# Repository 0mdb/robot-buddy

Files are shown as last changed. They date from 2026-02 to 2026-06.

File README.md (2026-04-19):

# Robot Buddy

A kid-safe, expressive robot platform combining real-time motor control, an animated TFT face, and optional networked AI planner.

## How It Works

Two ESP32-S3 microcontrollers handle the deterministic, safety-critical work: one drives motors with PID control and enforces safety limits, the other renders an animated face on a 320x240 TFT touch display (`esp32-face`). A Raspberry Pi 5 orchestrates everything at 50 Hz — reading sensors, running the state machine, applying layered safety policies, and streaming telemetry to a browser UI. An optional AI planner server on a separate machine (3090 Ti) generates expressive behavior plans via a local LLM.

Reflexes are local and deterministic. Planner is remote and optional.

## Hardware

| Component | Hardware | Role |
|---|---|---|
| Supervisor | Raspberry Pi 5 | 50 Hz orchestration, safety policy, HTTP/WS API |
| Face MCU | ESP32-S3 (ES3C28P) | 320x240 TFT face renderer + touch/buttons telemetry |
| Reflex MCU | ESP32-S3 WROOM | Differential drive, PID, encoders, IMU, ultrasonic, safety |
| AI Server | PC with 3090 Ti (off-robot) | Planner/conversation LLM + TTS on LAN (`LLM_BACKEND=ollama|vllm`) |
| Motor Driver | TB6612FNG | Dual H-bridge for differential drive |
| Power | 2S LiPo | Split into dirty (motors) and clean 5V regulated rails |

## Repository Layout

```
robot-buddy/
├── supervisor/       # Python supervisor (Raspberry Pi 5, process-isolated workers)
│   ├── core/            # 50 Hz tick loop, state machine, safety, behavior engine
│   ├── devices/         # MCU clients (reflex, face), protocol, expressions
│   ├── io/              # Serial transport, COBS framing, CRC
│   ├── workers/         # Process-isolated workers (TTS, vision, AI)
│   ├── messages/        # NDJSON envelope, event/action types
│   ├── api/             # FastAPI HTTP/WebSocket server, param registry
│   ├── mock/            # Mock Reflex MCU for testing (PTY-based)
│   ├── tests/           # pytest test suite
│   └── pyproject.toml   # Package metadata, deps
├── server/              # AI planner server (3090 Ti, FastAPI + backend switch)
│   ├── app/             # FastAPI app, LLM/STT/TTS backends, prompts, schemas
│   ├── tests/           # pytest test suite
│   ├── Modelfile        # Legacy Ollama model config
│   └── pyproject.toml   # Package metadata, deps
├── esp32-face/       # Face MCU firmware (ESP32-S3, C/C++, ESP-IDF)
│   └── main/            # TFT face rendering + touch/buttons + USB protocol
├── esp32-reflex/        # Reflex MCU firmware (ESP32-S3, C/C++, ESP-IDF)
│   └── main/            # Differential drive, PID, IMU, safety, encoders
├── dashboard/           # React dashboard (Vite + TypeScript + Biome)
│   └── src/             # Components, hooks, stores, tabs
├── specs/               # Completed specifications (immutable reference)
├── docs/                # TODO, architecture, protocols, wiring, power, research
├── deploy/              # Deployment (systemd service, install/update scripts)
├── tools/               # Dev utilities (face sim V3, parity check)
└── training/            # Wake word model training
```

## Architecture

```
┌──────────────────────────────────────────────────────┐
│ On Robot                                             │
│                                                      │
│  ┌────────────────────────────────────────────────┐  │
│  │ Raspberry Pi 5 — Supervisor                    │  │
│  │                                                │  │
│  │  50 Hz tick loop:                              │  │
│  │    read telemetry → state machine → safety     │  │
│  │    policies → send commands → broadcast        │  │
│  │                                                │  │
│  │  HTTP API (:8080)  WebSocket (:8080/ws)        │  │
│  │  Vision process (separate OS process, 10-20Hz) │  │
│  └──────┬──────────────────────┬──────────────────┘  │
│         │ USB serial (COBS)    │ USB serial (COBS)   │
│  ┌──────▼──────┐        ┌─────▼───────┐             │
│  │ Reflex MCU  │        │  Face MCU   │             │
│  │ ESP32-S3    │        │  ESP32-S3   │             │
│  │             │        │             │             │
│  │ Motors, PID │        │ 320x240 TFT │             │
│  │ Encoders    │        │ Face +      │             │
│  │ IMU, Range  │        │ Touch UI    │             │
│  │ Safety      │        │             │             │
│  └─────────────┘        └─────────────┘             │
└──────────────────────────────────────────────────────┘
         │
         │ HTTP (LAN, optional)
         │
┌────────▼───────────────────────────┐
│ AI Server (3090 Ti PC)             │
│                                    │
│ FastAPI planner server             │
│ LLM backend: ollama | vllm         │
│ TTS: Orpheus (vLLM) + espeak shed  │
│ POST /plan / WS /converse /tts     │
└────────────────────────────────────┘
```

### State Machine

`BOOT` → `IDLE` → `TELEOP` / `WANDER` → `ERROR`

- **BOOT → IDLE**: automatic when Reflex MCU connects with no faults
- **IDLE → TELEOP/WANDER**: via `set_mode` command
- **Any → ERROR**: on disconnect, ESTOP, TILT, or BROWNOUT
- **ERROR → IDLE**: via `clear_error()` when Reflex is healthy

### Safety Policies (Defense in Depth)

1. Mode gate — no motion outside TELEOP/WANDER
2. Fault gate — any fault → zero twist
3. Reflex disconnect → zero twist
4. Ultrasonic range scaling (hard stop at 250 mm, 50% at 500 mm)
5. Stale range fallback (50% cap)
6. Vision confidence scaling
7. Stale vision timeout (500 ms)

Safety-critical enforcement also runs on the Reflex MCU itself (acceleration limits, command TTL, hard stop). The supervisor applies additional caps above this.

### Serial Protocol

Binary packets over USB serial with COBS framing:

```
[type:u8][seq:u8][payload:N][crc16:u16-LE]
```

For `esp32-face`, this protocol carries face state/gesture/system/talking commands and touch/button/status telemetry only. Audio transport is supervisor-side USB audio.

Auto-reconnect with exponential backoff (0.5s–5s). See `docs/protocols.md` for packet definitions.

## Tech Stack

| Component | Stack |
|---|---|
| Supervisor | Python 3.11+, asyncio, FastAPI, uvicorn, pyserial, OpenCV |
| AI Server | Python 3.11+, FastAPI, httpx, Pydantic, Ollama (compat) + vLLM (migration target) |
| ESP32 Firmware | C/C++, ESP-IDF (FreeRTOS), CMake |
| Build (Python) | Hatchling via pyproject.toml, uv for dependency management |
| Build (ESP32) | `idf.py build` (CMake), `source ~/esp/esp-idf/export.sh` |
| Dashboard | React 19, Vite, TypeScript, Zustand, TanStack Query |
| Tests | pytest, pytest-asyncio, Vitest |
| Linting | ruff (Python), clang-format + cppcheck (C++), Biome (TypeScript) |

## Getting Started

### Supervisor (Raspberry Pi 5)

```bash
cd supervisor
uv sync --group dev

# Run with mock hardware (no physical robot needed)
just run-mock

# Run with real hardware
just run

# Other options
uv run python -m supervisor --no-vision         # Disable vision worker
uv run python -m supervisor --http-port 8080    # Custom HTTP port
uv run python -m supervisor --planner-api http://10.0.0.20:8100 --robot-id robot-1
```

### AI Planner Server (3090 Ti PC)

```bash
# Install and run the server
cd server
uv sync --extra dev --extra llm --extra stt --extra tts

# Recommended testing profile (vLLM planner + CPU STT + espeak)
LLM_BACKEND=vllm STT_DEVICE=cpu TTS_BACKEND=espeak \
uv run --extra llm --extra stt --extra tts python -m app.main
```

The server starts on port 8100. See `server/README.md` for full API docs and configuration.

### ESP32 Firmware

Requires ESP-IDF toolchain.

```bash
cd esp32-face   # or esp32-reflex
idf.py build
idf.py flash
idf.py monitor
```

### Dashboard

```bash
just run-dashboard         # dev server with hot reload
just build-dashboard       # production build → supervisor/static/
```

## Development

All commands are available via `just` (see `justfile`):

```bash
just test-all              # run all tests (supervisor, server, dashboard)
just lint                  # check Python + C++ + dashboard
just lint-fix              # auto-fix formatting
just preflight             # full pre-commit check (lint + tests + parity)
just sim                   # run face simulator V3
just check-parity          # verify sim↔MCU constant alignment
```

### Mock Mode

The supervisor includes a PTY-based mock Reflex MCU (`supervisor/mock/mock_reflex.py`) that simulates serial communication, telemetry, and fault injection. Use `just run-mock` to run the full supervisor stack without any hardware.

### Dashboard

When the supervisor is running, open `http://<robot_ip>:8080` in a browser for:
- Live telemetry display with diagnostic tree
- Mode control (IDLE, TELEOP, WANDER)
- E-STOP button
- Face control (moods, gestures, talking, conversation state)
- Parameter tuning sliders (PID gains, speed limits, safety thresholds)
- Monitor tab (device health, comms, power, sensors, faults, workers)
- MJPEG video stream (if vision enabled)

### Configuration

**Supervisor** — YAML config file (schema in `supervisor/config.py`):
- Sections: serial, control, safety, network, logging, vision
- Default serial paths: `/dev/robot_reflex`, `/dev/robot_face` (via udev symlinks)

**AI Server** — environment variables:
- `LLM_BACKEND`, `VLLM_MODEL_NAME`, `LLM_MAX_INFLIGHT`, `PERFORMANCE_MODE`
- legacy compatibility: `OLLAMA_URL`, `MODEL_NAME`, `PLAN_TIMEOUT_S`, `TEMPERATURE`, `NUM_CTX`
- See `server/README.md` for the full table

**ESP32** — `sdkconfig.defaults` + `config.h` constants

## Supervisor API

| Endpoint | Method | Description |
|---|---|---|
| `/status` | GET | Current robot state (JSON) |
| `/params` | GET | Full parameter registry |
| `/params` | POST | Transactional parameter updates |
| `/actions` | POST | RPC: `set_mode`, `e_stop`, `clear_e_stop` |
| `/video` | GET | MJPEG stream (if vision enabled) |
| `/debug/devices` | GET | Device connection state |
| `/debug/planner` | GET | Planner state |
| `/debug/mcu_benchmark` | GET | MCU benchmark run status |
| `/ws` | WS | Telemetry stream (20 Hz, JSON) |
| `/ws/logs` | WS | Live log stream |

## AI Server API

| Endpoint | Method | Description |
|---|---|---|
| `/health` | GET | Server + selected LLM backend status |
| `/plan` | POST | Accept world state + `robot_id/seq/monotonic_ts_ms`, return plan + `plan_id` echo metadata |
| `/converse` | WS | Conversation stream (single active session per `robot_id`) |
| `/tts` | POST | Direct TTS with optional metadata (`robot_id`, `seq`, `monotonic_ts_ms`) |

Plan actions: `say(text)`, `emote(name, intensity)`, `gesture(name, params)`, `skill(name)` — planner proposes intent and supervisor executes deterministic skills.

## Supervisor Fallback Policy

| Failure condition | Immediate supervisor action | Motion policy | Face policy | Speech policy |
|---|---|---|---|---|
| `/plan` unreachable / non-200 | Mark planner disconnected; skip remote plan apply | Local deterministic only (`patrol_drift`/`avoid_obstacle`/safe stop) | `confused` gesture with cooldown | Cancel queued planner speech |
| `/converse` TTS fails mid-turn | Stop playback and clear talking flag | No change to motion authority | Show `thinking` briefly then restore previous mood | Attempt fallback backend once; if unavailable, skip speech |

## Project Status

### Working
- [x] Supervisor: 50 Hz control loop, state machine, safety policies, conversation state, mood choreography
- [x] Supervisor: serial transport with COBS framing, CRC, auto-reconnect, protocol v2 (timestamps + seq)
- [x] Supervisor: FastAPI HTTP/WebSocket API with telemetry streaming
- [x] Supervisor: process-isolated workers (TTS, vision, AI, ear)
- [x] Supervisor: mock Reflex MCU for hardware-free development
- [x] AI Server: FastAPI + vLLM planner (Qwen), conversation, TTS (Orpheus + espeak)
- [x] ESP32 Face: TFT face rendering, 13 moods, 13 gestures, conversation border, touch/button telemetry
- [x] ESP32 Reflex: motor control, PID, encoders, IMU, safety enforcement
- [x] Dashboard: React 19, live telemetry, face control, monitor tab, mode control
- [x] Voice pipeline: wake word ("hey buddy") + VAD → STT → LLM → TTS → face animation
- [x] WANDER mode driven by deterministic skills + planner intent
- [x] Deterministic telemetry: timestamps, sequence numbers, clock sync, raw packet logging

### In Progress
- [ ] Reflex MCU hardware commissioning (breadboard bring-up)
- [ ] Personality engine implementation (spec complete, implementation pending)

### Future
- [ ] Conversation memory / interaction history
- [ ] Wake word model improvements (recall 42% → 80%+)
- [ ] Additional modes: LINE_FOLLOW, BALL, CRANE, CHARGING
- [ ] Home Assistant integration
- [ ] Voice ID / speaker identification

See [docs/TODO.md](docs/TODO.md) for the detailed backlog and [specs/](specs/) for design specifications.

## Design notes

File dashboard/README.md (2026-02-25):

# Robot Buddy Dashboard

Web dashboard for the Robot Buddy supervisor. Replaces the old single-file HTML dashboard entirely — `npm run build` outputs to `supervisor/static/` which FastAPI serves at `/`.

## Quick Start

### Development (with hot reload)

```bash
cd dashboard
npm install
npm run dev
```

Opens at `http://localhost:5173/`. Vite proxies all API/WS calls to the Pi at `192.168.55.100:8080` (configured in `vite.config.ts`).

### Production Build

```bash
cd dashboard
npm run build
```

Outputs to `../supervisor/static/`. The supervisor serves it automatically — no separate web server needed.

## Tabs

| Tab | What it does |
|---|---|
| **Drive** | Joystick (touch + mouse), mode buttons (IDLE/TELEOP/WANDER), E-STOP, sparkline gauge cards (speeds, gyro, range, battery, tick dt), fault badges, speed caps, video feed toggle |
| **Telemetry** | 4 uPlot time-series charts (wheel speeds, rotation, range, battery) with adjustable window (30s/60s/120s) and pause/resume |
| **Devices** | Reflex/Face MCU cards (packet counts, seq, age), clock sync (offset, RTT, drift), transport stats. Polled at 2s via `/debug/devices` + `/debug/clocks` |
| **Logs** | Live log stream via `WS /ws/logs`. Virtualized list (react-window, 5000 entries). Level filter buttons, text search, edge-aware pin auto-scroll (top in `Newest`, bottom in `Oldest`), click-to-expand detail panel |
| **Calibration** | PID tuner (kV, kS, Kp, Ki, K_yaw + rate limits), Vision/HSV sliders, Range thresholds, IMU panel. Debounced 150ms with Apply for batch updates |
| **Parameters** | AG Grid table of all params. Grouped by owner, quick filter search, inline edit with debounced POST, safety badges |
| **Face** | Mood/intensity/gaze/brightness, 13 gesture buttons, system mode, talking + energy, 7 flag toggles, manual lock |

## Tech Stack

| Concern | Library |
|---|---|
| Framework | React 19 + TypeScript |
| Build | Vite 7 |
| State | Zustand 5 |
| Data fetching | React Query 5 (debug endpoints, params) |
| Charts | uPlot (imperative, ~35 KB, bypasses React for 20 Hz data) |
| Tables | AG Grid Community 35 (params) |
| Virtualized lists | react-window 2 (log viewer) |
| Styling | CSS Modules (dark theme) |

## Architecture

### Data Flow

```
Pi supervisor (50 Hz tick loop)
  └─ WS /ws ──── 20 Hz telemetry JSON ────► wsManager.ts ──► telemetryStore (Zustand)
  └─ WS /ws/logs ── log entries JSON ──────► wsLogs.ts ────► logStore (Zustand)
  └─ REST /debug/* ── polled 2s ───────────► React Query ──► DevicesTab / ClocksTab
  └─ REST /params ── on demand ────────────► React Query ──► ParamsTab (AG Grid)
```

### Key Design Decisions

- **Float64Array ring buffers** — 1200 samples per metric (60s @ 20Hz), zero GC pressure during ingestion
- **Charts bypass React** — uPlot updates via `zustand.subscribe()` at 5 Hz, no React reconciliation
- **Gauges throttled to 10 Hz** — `useTelemetry(selector, 100)` hook with `useSyncExternalStore`
- **Joystick uses throttle (not debounce)** — steady 10 Hz while dragging, immediate `{v:0, w:0}` on release
- **WebSocket reconnect with exponential backoff** — 0.5s to 8s cap, `ws_connected` only after first valid telemetry
- **Page Visibility API** — ring buffers keep filling when tab is backgrounded, charts force redraw on foreground return
- **Cache headers** — `index.html` served with `no-cache`; hashed asset filenames are safe to cache forever

## Project Structure

```
dashboard/
├── src/
│   ├── App.tsx                    # Tab layout, WS lifecycle
│   ├── types.ts                   # All TypeScript interfaces
│   ├── constants.ts               # Faults, moods, gestures, face flags
│   ├── stores/
│   │   ├── telemetryStore.ts      # Snapshot + ring buffers + WS meta
│   │   └── uiStore.ts            # Active tab, video toggle
│   ├── lib/
│   │   ├── ringBuffer.ts         # Float64Array circular buffer
│   │   ├── wsManager.ts          # WS with reconnect + backoff
│   │   ├── wsLogs.ts             # Log WS + log store
│   │   ├── throttle.ts           # Joystick throttle
│   │   └── debounce.ts           # Slider/param debounce
│   ├── hooks/
│   │   ├── useTelemetry.ts       # Throttled selector
│   │   ├── useWsMeta.ts          # WS health (age, gaps, reconnects)
│   │   ├── useSend.ts            # WS command sender
│   │   ├── useDevices.ts         # React Query: /debug/devices
│   │   ├── useClocks.ts          # React Query: /debug/clocks
│   │   └── useParams.ts          # React Query: /params GET + POST
│   ├── components/
│   │   ├── Header.tsx            # WS status, telemetry age, faults
│   │   ├── TabBar.tsx            # 7-tab navigation
│   │   ├── Sparkline.tsx         # Tiny uPlot (transient updates)
│   │   ├── TimeSeriesChart.tsx   # Full uPlot (transient updates)
│   │   ├── Joystick.tsx          # Canvas, touch + mouse
│   │   └── FaultBadges.tsx       # Decoded fault flags
│   ├── tabs/                     # One file per tab
│   └── styles/                   # CSS Modules (dark theme)
├── vite.config.ts                # Build → ../supervisor/static/
└── package.json
```

## Scripts

```bash
npm run dev          # Vite dev server with HMR + proxy to Pi
npm run build        # TypeScript check + production build
npm run typecheck    # TypeScript only (no emit)
npm run lint         # Biome lint
npm run lint:fix     # Biome lint + autofix
npm run format       # Biome format
npm run test         # Vitest
npm run preview      # Preview production build locally
```

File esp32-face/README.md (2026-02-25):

# esp32-face

ESP32-S3 firmware for Robot Buddy face rendering + supervisor link.

## Scope

- Face animation renderer (landscape 320×240, ILI9341)
- Sim V3 animation parity target (13 moods, gestures, system face screens, talking modulation)
- USB CDC command/telemetry protocol
- Touch telemetry + corner button hit-testing
- Pixel-rendered corner button controls (SDF icons, not LVGL widgets):
  - bottom-left `PTT` (MIC icon, 60×46 px zone, tap-toggle listening)
  - bottom-right `ACTION` (X_MARK icon, 60×46 px zone, click event)
  - Icon/state/color driven automatically by conversation state
  - Suppressed (hidden + hit-testing disabled) during system overlays
- Conversation border renderer (SDF frame + glow, 8 conv states)
- WS2812 status LED:
  - talking: orange
  - listening: blue
  - idle: green

Audio codec/microphone handling was removed from this firmware. Audio is owned by supervisor-side USB devices.

## System Screens

System modes drive Buddy's face expression (eyes, mouth, eyelids, color) rather than abstract overlays — matching the Sim V3 approach. Implemented in `system_face.cpp`:

| Mode | Expression | Color | Duration |
|---|---|---|---|
| BOOTING | Sleepy slits → yawn → blink → happy bounce | Navy → cyan | 3.0 s |
| ERROR_DISPLAY | Confused face + slow headshake | Warm orange | Continuous |
| LOW_BATTERY | Sleepy with droopy eyelids + periodic yawns | Navy (dims with charge) | Continuous |
| UPDATING | Thinking expression, gaze drifts up-right | Blue-violet | Continuous |
| SHUTTING_DOWN | Yawn → droop → eyes close → fade to black | Cyan → navy → black | 2.5 s |

Small SDF icon overlays appear in the lower-right corner: warning triangle (error), battery bar (low battery), progress bar (updating).

The legacy abstract overlay renderer (`system_overlay_v2.cpp`) is retained but no longer called from the render path.

## Command Path Reliability

- `SET_STATE`, `SET_SYSTEM`, `SET_TALKING` use latched channels (latest value wins).
- `GESTURE` uses a FIFO queue for one-shot animations.
- This prevents high-rate talking energy updates from dropping mood/system/gesture commands.

## Rendering Note

- The face canvas uses explicit `LV_COLOR_FORMAT_RGB565` to match the ILI9341 panel format.
- This keeps the render path in native panel format and avoids extra color conversion work.

## Current Parity Gaps

- Face center rendering is not pixel-for-pixel with sim V3 (SDF eye/mouth rasterization differences remain)
- Some sim↔MCU timing divergences documented in [docs/TODO.md](../docs/TODO.md)
- Stage 4 firmware optimization planned (dirty-rect, DMA, RGB565 dithering)

## Protocol

Commands (host → face):

- `0x20` `SET_STATE` — mood, intensity, gaze, brightness
- `0x21` `GESTURE` — one-shot animation (FIFO queue)
- `0x22` `SET_SYSTEM` — system mode + param (boot, error, battery, updating, shutdown)
- `0x23` `SET_TALKING` — lip sync (talking flag + energy)
- `0x24` `SET_FLAGS` — feature toggles (blink, wander, sparkle, afterglow, edge glow)
- `0x25` `SET_CONV_STATE` — conversation border state (0–7)

Telemetry (face → host):

- `0x90` `FACE_STATUS` (20 Hz, v1=4B or v2=12B with command-causality fields)
- `0x91` `TOUCH_EVENT` (on change)
- `0x92` `BUTTON_EVENT` (on change)
- `0x93` `HEARTBEAT` (1 Hz, 68B base + optional perf tail)

## Build

```bash
idf.py build
```

## Flash + Monitor

```bash
idf.py -p /dev/ttyACM0 flash monitor
```

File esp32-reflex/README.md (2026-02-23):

# esp32-reflex

ESP32-S3 (Reflex MCU) firmware: owns motors, encoders, and safety.

Design goal: **deterministic motion control** with reliable feedback, smooth starts/stops, and hard safety guarantees. Supervisor (Raspberry Pi 5) sends high-level velocity targets; MCU owns PWM, PID, and stop behavior.

---

## Framework
- ESP-IDF (FreeRTOS)
- Motors: LEDC PWM + GPIO direction into TB6612FNG
- Encoders: PCNT (quadrature) for each wheel
- Control loop: 100–200 Hz speed PID (closed-loop)
- Transport: USB serial (binary protocol)

---

## Hardware
- Differential drive (left/right motors)
- TT gear motors with integrated quadrature encoders
- Motor driver TB6612FNG
- 2S battery pack
- BMI270 IMU (gyro + accelerometer, 400 Hz ODR)
- Ultrasonic range sensor

---

## Control Philosophy
### Reflexes stay local
- The MCU is responsible for **stable motion** regardless of supervisor load.
- No real-time PWM from supervisor. Ever.

### Interfaces are narrow and stable
- Supervisor commands *intent*: `SET_TWIST(v, w)`, `STOP()`
- MCU returns *truth*: wheel speed, gyro, battery, faults

---

## Motion Stack (v1)
1) **Command layer**
- `SET_TWIST(v_mm_s, w_mrad_s)` target
- Convert to wheel speed targets using wheelbase & wheel radius

2) **Rate limiting**
- Acceleration / jerk limiting on wheel targets
- Prevents brownouts, reduces stalls, kid-safe motion

3) **Speed PID (per wheel)**
- Inputs: encoder counts over dt
- Output: PWM duty (signed)
- Anti-windup + output saturation
- Deadband compensation (optional)

4) **Safety**
- Command timeout -> controlled stop (ramp down)
- Watchdog
- Fault flags -> forced stop

---

## Advanced Features (only if they earn their keep)
### A) Slip / traction heuristics (low-cost, optional)
Without an IMU, "traction control" is limited. What we *can* do:
- Detect wheel-speed mismatch under commanded straight motion
- Detect stall (commanded speed high, measured ~0 for N ms)
- Apply corrective action:
  - reduce accel
  - clamp max PWM
  - pulse-retry pattern
This is practical and improves robustness, but it’s not true traction control.

### B) IMU-assisted yaw damping (implemented)
BMI270 IMU is integrated. Current implementation:
- Gyro-Z feedback for yaw damping in the control loop
- 400 Hz ODR, ±500 dps gyro range, ±4g accel range

### C) Battery-aware torque limiting (high leverage)
- Monitor battery voltage
- If sag detected: reduce accel / max PWM to avoid Pi 5 brownouts
This is *very* useful in kid scenarios (stalls, carpet, low battery).

### D) Odometry (recommended once encoders are stable)
- Integrate wheel distances -> (x, y, theta)
- Provide odom to Pi 5 for higher-level behavior
Note: odom on tracks drifts; still valuable.

---

## Protocol (Supervisor ↔ Reflex MCU)
Binary packets, fixed-size, no JSON.

### Commands
- `SET_TWIST(v_mm_s: i16, w_mrad_s: i16)`
- `STOP(reason: u8)`
- `SET_MODE(mode: u8)` (future: safe/normal/turbo)
- `SET_LIMITS(max_v, max_a, max_pwm)` (optional)

### Telemetry
- wheel_speed_l/r (i16)
- encoder_counts_l/r (i32)
- battery_mv (u16) (optional but recommended)
- fault_flags (u16)
- (future) odom x/y/theta

---

## Tasks / Timing (suggested)
- `usb_serial_task`: parse commands, publish targets
- `control_task` @ 100–200 Hz:
  - read encoders (PCNT snapshot)
  - compute wheel speeds
  - apply rate limit
  - run PID
  - write PWM + direction
- `safety_task` @ 10–50 Hz:
  - command timeout
  - battery checks
  - fault handling
- optional `telemetry_task` @ 10–20 Hz

No blocking in the control loop.

---

## Fault Model (v1)
- `FAULT_CMD_TIMEOUT`
- `FAULT_ENCODER_MISSING`
- `FAULT_STALL_LEFT / FAULT_STALL_RIGHT`
- `FAULT_BATT_LOW` (if battery sense)
- `FAULT_ESTOP`

Faults force stop or limit mode depending on severity.

---

## Completed
- [x] Motor driver pinout + open-loop control (LEDC PWM + GPIO direction into TB6612FNG)
- [x] Encoders with PCNT (quadrature, per wheel) + wheel speed measurement
- [x] Per-wheel FF+PI speed control @ 100 Hz
- [x] Acceleration limiting / ramping (kid-safe, power-safe)
- [x] Stall detection + safe recovery
- [x] STOP behavior (ramped stop, brake/coast)
- [x] Command timeout → safe stop
- [x] Watchdog integration (esp_task_wdt)
- [x] E-stop + fault flags → forced stop
- [x] USB serial binary protocol (COBS + CRC16) to supervisor
- [x] Telemetry packets (STATE: speeds, gyro, battery, faults, range)
- [x] BMI270 IMU integration (gyro-Z yaw damping)

## TODO

See [docs/TODO.md](../docs/TODO.md) for the full backlog. Key remaining items for reflex:
- Battery voltage sense (ADC) + sag-aware limiting
- Odometry integration (x, y, theta)
- Full IMU heading hold PID (currently gyro damping only)
- Hardware commissioning (Phases 1-5)

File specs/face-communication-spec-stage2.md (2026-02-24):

# Face Communication Spec — Stage 2: Full Specification

**Prerequisite**: Stage 1 (Research & Design Approach Proposal) — all decisions approved 2026-02-21.

**Scope**: This document defines the complete visual language for the robot face — every expression, transition, timing rule, and protocol mapping needed to implement "intention and awareness" for children ages 4–6. All values are implementation-ready. All claims are evidence-tagged per Stage 1 rigor constraints.

**Companion documents**: Stage 2 Implementation Plan, Stage 2 Evaluation Plan (separate files).

---

## 1. Personality Profile

**Relational role**: Caretaker/guide with playful elements. Predominantly calm and reassuring. Emotional authority is higher than the child's — the robot's affect should not destabilize.

**Axis positions** (0.0 = low end, 1.0 = high end per [S1-C3] definitions):

| Axis | Position | Rationale |
|---|---|---|
| **Energy Level** | 0.40 | Calm baseline with enough responsiveness to feel warm, not sluggish. Caretaker pacing — slightly slower than the child's energy. **[Inference]** |
| **Emotional Reactivity** | 0.50 | Moderate — expressive enough to validate the child's emotions, restrained enough not to mirror distress. **[Empirical]** Kahn et al. (2012) shows children attribute real feelings to robots. **[Inference]** We set reactivity at 0.50 to prevent over-attribution while remaining warm. Must be validated in T4 child evaluation. |
| **Social Initiative** | 0.30 | Mostly responsive. Initiates only through idle aliveness cues (breathing, gaze wander), not through autonomous mood changes or attention-seeking gestures. **[Empirical]** Leite et al. (2013) notes proactive behaviors sustain engagement but risk habituation. **[Inference]** We set initiative at 0.30 to stay responsive without risking habituation. |
| **Vulnerability Display** | 0.35 | Lightly guarded. Can show confusion (THINKING mood) and mild concern but avoids overt sadness, fear, or anger outside conversation context. Consistent with caretaker authority. **[Inference]** |
| **Predictability** | 0.75 | High consistency. Same conversation phase → same core face behavior. Variation limited to cosmetic parameters per D10:B. **[Empirical]** Kanda et al. (2004) shows consistency builds trust over repeated interactions. **[Inference]** We set predictability at 0.75, reserving 0.25 for cosmetic variation (blink, breathing, sparkle) that provides aliveness without semantic variability. |

**Design implications of this profile**:
- Transitions are smooth, never snappy (Energy 0.40)
- Emotional onset is gradual, not instant (Reactivity 0.50)
- Robot never autonomously changes mood outside conversation (Initiative 0.30)
- Negative emotions are always brief, contextualized, and recovered (Vulnerability 0.35)
- A child who interacts daily should develop reliable expectations (Predictability 0.75)

---

## 2. Intent Taxonomy

Everything the face must communicate, classified by temporal profile.

### 2.1 Tonic Intents (Sustained States)

Held for extended periods. The face "rests" in one of these.

| Intent | Description | Primary Channel | Duration |
|---|---|---|---|
| **Idle** | Robot is on, no conversation active | Eyes (neutral) + breathing + blink + gaze wander | Indefinite |
| **Conversation: Listening** | Child is speaking, robot is attending | Gaze (center lock) + border (teal breathing) + LED | Until VAD end-of-utterance |
| **Conversation: PTT** | Tap-to-talk active | Gaze (center lock) + border (amber steady) + LED | Until toggled off |
| **Conversation: Thinking** | Processing user input | Gaze (aversion) + border (blue-violet orbit) + LED | Until TTS starts (~1–3 s typical) |
| **Conversation: Speaking** | TTS playback active | Mouth (lip sync) + border (white-teal energy) + LED | Until TTS finishes |
| **Emotion** | AI/planner-set mood | Eyes + mouth + face color | Until next mood command or recovery |
| **System overlay** | BOOTING, ERROR, LOW_BATTERY, UPDATING, SHUTTING_DOWN | Face-based expression + status icon (§4.4) | Until condition clears |

### 2.3 Layer Interaction Rules

The conversation layer can temporarily **clamp** the emotion layer during specific phases. This resolves the tension between emotion as a tonic intent ("until next mood command") and conversation states that force specific moods.

| Conversation Phase | Emotion Layer Status | Behavior |
|---|---|---|
| **LISTENING / PTT** | Suppressed | Face shows attentive neutral (NEUTRAL @ 0.3). The personality worker continues integrating AI emotion impulses into the affect vector, but the tick loop does not display the worker's projected mood during this phase. |
| **THINKING** | Suppressed | Face shows THINKING mood @ 0.5. The personality worker continues integrating impulses. |
| **SPEAKING** | **Active** | Tick loop reads the personality worker's current snapshot and displays its projected mood via mood switch choreography (§5.1.1). The snapshot already reflects all impulses integrated during LISTENING/THINKING — no explicit queue or replay step. |
| **ATTENTION** | Held | Current mood held unchanged. |
| **ERROR** | Held | Current mood held unchanged. |
| **DONE** | Released | Mood intensity ramps to 0.0 (return to neutral). The personality worker's affect vector decays naturally toward baseline. Emotion layer returns to idle control. |

**Rationale**: During LISTENING and THINKING, the child sees the robot "paying attention" and "processing" — these are social signals that should not be contaminated by premature emotion display. Emotions become visible during SPEAKING, when the audio context makes them legible (per Denham, 1986: children use context + face together).

**Suppress-then-read model**: The personality worker's affect integrator runs continuously during LISTENING/THINKING (PE spec §10). AI emotion impulses are integrated immediately — they are never buffered in a queue. The integrator provides natural smoothing: if the AI sends HAPPY during LISTENING and then SAD during THINKING, the affect vector ends up between them (weighted by decay and recency), producing emotionally coherent behavior. On SPEAKING entry, the tick loop reads the worker's current snapshot, which already reflects all integrated impulses.

### 2.2 Phasic Intents (Transient Events)

Brief events that overlay or punctuate tonic states.

| Intent | Description | Duration | Trigger |
|---|---|---|---|
| **Acknowledgment** | "I heard you" response to wake word or PTT press | 400 ms | Wake word detection / PTT down |
| **Mood transition** | Choreographed switch between emotions | 350–550 ms | SET_STATE with new mood_id |
| **Conversation phase transition** | Visual bridge between conversation states | 200–500 ms | State machine edge |
| **Gesture** | One-shot expressive animation (blink, nod, laugh, etc.) | 180 ms – 3.0 s | GESTURE command |
| **Negative affect recovery** | Mandatory return to neutral/positive after negative mood | 300–500 ms | Guardrail timer expiry |
| **Error flash** | Brief visual error indicator | 800 ms | Conversation error event |

---

## 3. Channel Allocation Policy

**Policy**: Hybrid ([S1-C4], informed by [S1-D1]:A, [S1-D3]:C, [S1-D5]:A, [S1-D6]:C).

### 3.1 Channel Ownership Table

| Channel | Emotion Layer | Conversation Layer | System Layer | Idle Layer |
|---|:---:|:---:|:---:|:---:|
| **Eyes (shape, eyelids)** | OWNS | mood hints only | overlay | neutral defaults |
| **Mouth (curve, open, width)** | OWNS | — | overlay | neutral defaults |
| **Gaze (eye position)** | — | All active conv states (extended from D6:C) | — | OWNS (wander) |
| **Face color** | OWNS | — | overlay | neutral color |
| **Border** | — | OWNS | — | off |
| **LED** | — | OWNS (mirrors border) | override | off |
| **Backlight** | — | — | OWNS | default brightness |

**Collision rules** (highest priority wins):
1. System overlay → overrides everything
2. Talking animation → overrides mouth (lip sync), coexists with emotion eyes
3. Conversation gaze → overrides idle gaze wander during all active conversation states (ATTENTION, LISTENING, PTT, THINKING, SPEAKING, ERROR). [S1-D6]:C specified "hybrid, incrementally extensible" — extended to all states for coherence.
4. Conversation border/LED → independent channel, no collision with emotion
5. Emotion → sets eyes/mouth/face color
6. Idle → fills anything not claimed above

### 3.2 Semantic vs Cosmetic Parameters (D10:B)

**Semantic** (deterministic — same input → same output):
- Mood selection (mood_id)
- Mood intensity target
- Conversation state (border color, animation type)
- Gaze target during LISTENING (center)
- Gaze direction during THINKING (aversion target)
- Transition choreography sequence
- Negative affect guardrail timers

**Cosmetic** (bounded stochastic — jitter permitted):
- Blink interval (2.0–5.0 s, uniform random)
- Idle gaze wander target (random within ±MAX_GAZE)
- Idle gaze wander interval (1.5–4.0 s, uniform random)
- Saccade micromotion (existing MCU implementation)
- Breathing phase (continuous, free-running)
- Sparkle activation (Bernoulli per frame, p=0.05)
- Sparkle position (uniform random across screen)

---

## 4. Visual Grammar

### 4.1 Emotion Expressions

#### 4.1.1 Mood Classification

| Class | Moods | Autonomous Use | Guardrails |
|---|---|---|---|
| **Positive** | HAPPY, EXCITED, LOVE, SILLY | Unrestricted | None |
| **Neutral** | NEUTRAL, CURIOUS, THINKING, SLEEPY, SURPRISED, CONFUSED | Unrestricted | SURPRISED: startle reflex safety (§7.4) |
| **Negative** | SAD, SCARED, ANGRY | Conversation context only (D2:B) | See §7 |

**[Empirical]** Widen & Russell (2003): Children ages 4–6 reliably label happy, sad, angry, scared. Surprise and disgust are often confused. This informs the "safe set" — HAPPY, SAD, ANGRY, SCARED are the most legible. SURPRISED requires extra disambiguation via context.

**SURPRISED reclassification**: PE spec §4.1 places SURPRISED at (V=+0.15, A=+0.80) — positive valence, high arousal. Classifying it as Neutral is more principled than the original Negative classification, since surprise is positive-valent and often positive-contextual. High arousal warrants a safety cap (§7.4), but not a negative-affect guardrail.

**CONFUSED**: Added per PE spec §4.1 (V=-0.20, A=+0.30). Mild negative valence, low arousal — conveys uncertainty without distress. Classified as Neutral because the expression reads as "uncertain/puzzled" rather than "upset."

**[Empirical]** Di Dio et al. (2020): On stylized robot faces, children 4–8 achieve 68–99% recognition accuracy. Happiness and sadness are easiest (>90%); anger and fear are moderate (70–85%); surprise is hardest (<70%).

#### 4.1.2 Mood Parameter Targets

All parameters blend from neutral baseline via intensity (§4.1.3). Values are the full-intensity (1.0) targets.

| Mood | mouth_curve | mouth_width | mouth_open | lid_slope | lid_top | lid_bot | Face Color (R,G,B) |
|---|:---:|:---:|:---:|:---:|:---:|:---:|:---:|
| NEUTRAL | 0.1 | 1.0 | 0.0 | 0.0 | 0.0 | 0.0 | (50, 150, 255) |
| HAPPY | 0.8 | 1.1 | 0.0 | 0.0 | 0.0 | 0.4 | (0, 255, 200) |
| EXCITED | 0.9 | 1.2 | 0.2 | 0.0 | 0.0 | 0.3 | (100, 255, 100) |
| CURIOUS | 0.0 | 0.9 | 0.0 | -0.3 | 0.0 | 0.0 | (255, 180, 50) |
| SAD | -0.5 | 1.0 | 0.0 | -0.6 | 0.3 | 0.0 | (50, 80, 200) |
| SCARED | -0.3 | 0.8 | 0.3 | 0.0 | 0.0 | 0.0 | (180, 50, 255) |
| ANGRY | -0.6 | 1.0 | 0.0 | 0.8 | 0.4 | 0.0 | (255, 0, 0) |
| SURPRISED | 0.0 | 0.4 | 0.6 | 0.0 | 0.0 | 0.0 | (255, 255, 200) |
| SLEEPY | 0.0 | 1.0 | 0.0 | -0.2 | 0.6 | 0.0 | (40, 60, 100) |
| LOVE | 0.6 | 1.0 | 0.0 | 0.0 | 0.0 | 0.3 | (255, 100, 150) |
| SILLY | 0.5 | 1.1 | 0.0 | 0.0 | 0.0 | 0.0 | (200, 255, 50) |
| THINKING | -0.1 | 1.0 | 0.0 | 0.4 | 0.2 | 0.0 | (80, 135, 220) |
| CONFUSED | -0.2 | 1.0 | 0.0 | -0.15 | 0.1 | 0.0 | (200, 160, 80) |

**CONFUSED design rationale**: Mild furrowed brow (lid_slope -0.15), slightly raised upper lid (0.1). Very slight frown (mouth_curve -0.2), mouth closed. Warm amber-brown face color, distinct from all other moods. Less expressive than CURIOUS (lid_slope -0.3) to convey "uncertain" rather than "interested." Note: the CONFUSED *gesture* (GestureId::CONFUSED = 3) already exists and is distinct from this sustained *mood*. **[Provisional]** Parameters need sim prototyping in Stage 3 and child recognition testing in T3/T4 evaluation.

*Source: Verified from `face_state.cpp:257–321` and `face_state.cpp:620–680`.*

#### 4.1.3 Intensity Blending

**Mechanism** (D8:C — discrete with intensity blending):

```
displayed_value = neutral_value + (mood_target - neutral_value) × intensity
```

Applied identically to all 6 face parameters and to face color (RGB channels independently).

**Neutral baseline values**:
- mouth_curve: 0.1, mouth_width: 1.0, mouth_open: 0.0
- lid_slope: 0.0, lid_top: 0.0, lid_bot: 0.0
- Face color: (50, 150, 255) — cyan-blue

**Intensity range**: 0.0 (fully neutral) to 1.0 (full expression). Wire encoding: uint8 0–255.

**Typical intensity values**:
- AI conversation emotion: 0.7 (allows headroom for gesture overlay)
- Planner emotion: 0.5–1.0 (context-dependent)
- Recovery target: 0.0 (returns face to neutral)

### 4.2 Conversation State Signaling

**[Empirical]** Löffler et al. (2018): Color + motion multimodal coding offers the best cost/benefit ratio for robot emotion expression. Redundant cues across channels improve recognition. This supports the multimodal approach (D3:C) — border + LED + gaze + mood hints for each state.

**[Empirical]** Andrist et al. (2014): Gaze aversion during cognitive processing (thinking) is expected by humans and helps regulate turn-taking. Direct gaze during listening signals attention.

#### 4.2.1 State Definitions

Eight conversation states, matching the sim prototype (`conv_border.py:25–33`):

```
IDLE → ATTENTION → LISTENING → THINKING → SPEAKING → DONE → IDLE
                 ↘ PTT ↗                  ↗ ERROR ↗
```

#### 4.2.2 Per-State Visual Specification

**IDLE** (no conversation active)

| Channel | Behavior |
|---|---|
| Border | Off (alpha = 0) |
| LED | Off (0, 0, 0) |
| Gaze | MCU idle wander (1.5–4.0 s interval, spring dynamics) |
| Mood | Last set mood, or NEUTRAL if none |
| Flags | All idle defaults: IDLE_WANDER=1, AUTOBLINK=1, SPARKLE=1 |

---

**ATTENTION** (wake word detected or PTT first press — acknowledgment phase)

| Channel | Behavior |
|---|---|
| Border | Flash to light cyan (180, 240, 255), inward sweep animation over 400 ms |
| LED | Light cyan at 16% border alpha |
| Gaze | Snap to center (0, 0) — supervisor sends gaze override |
| Mood | Hold current mood (no change) |
| Flags | IDLE_WANDER=0 (disable wander for gaze lock) |
| Duration | 400 ms, then auto-advance to LISTENING |

**Awareness indicators addressed**: Acknowledgment (immediate visual response to wake word), temporal correlation (face changes synchronized with trigger).

**Timing budget**: Wake word detection latency (~80 ms frame + inference) + supervisor event propagation (~20 ms tick) + MCU render (~33 ms) = ~133 ms worst case from speech end to first visible pixel change. Well within the 200–300 ms perceptual threshold for "immediate" response. **[Inference — needs measurement]**

---

**LISTENING** (child is speaking, robot is attending)

| Channel | Behavior |
|---|---|
| Border | Teal (0, 200, 220), breathing alpha: 0.6 + 0.3 × sin(t × 2π × 1.5) |
| LED | Teal at 16% of border alpha |
| Gaze | Center lock (0, 0) — supervisor overrides MCU idle wander (D6:C) |
| Mood | NEUTRAL at intensity 0.3 (attentive neutral — slight engagement) |
| Flags | IDLE_WANDER=0, AUTOBLINK=1 |

**Awareness indicators addressed**: Gaze coherence (eyes locked on user), state continuity (steady breathing border).

**[Empirical]** Admoni & Scassellati (2017): Direct gaze signals attention and willingness to engage. During listening, the robot's gaze should be directed at the speaker.

---

**PTT** (tap-to-talk — variant of listening, toggled on/off by tapping PTT button)

| Channel | Behavior |
|---|---|
| Border | Warm amber (255, 200, 80), subtle pulse: 0.8 + 0.1 × sin(t × 2π × 0.8) |
| LED | Amber at 16% of border alpha |
| Gaze | Center lock (0, 0) |
| Mood | NEUTRAL at intensity 0.3 |
| Flags | IDLE_WANDER=0, AUTOBLINK=1 |

Visually distinct from LISTENING (amber vs teal) so the child/parent can confirm PTT is active. Same gaze and mood behavior.

---

**THINKING** (processing user input, waiting for AI response)

| Channel | Behavior |
|---|---|
| Border | Blue-violet (120, 100, 255), orbiting comet dots: 3 dots, 0.5 rev/s, base alpha 0.3 |
| LED | Blue-violet at 16% of border alpha |
| Gaze | Aversion — look up-right (gaze_x = +0.5, gaze_y = -0.3) — supervisor sends explicit target |
| Mood | THINKING at intensity 0.5 (mild: slight lid droop + slight frown) |
| Flags | IDLE_WANDER=0, AUTOBLINK=1 |

**[Empirical]** Andrist et al. (2014): Gaze aversion during processing is natural and expected. Looking away signals "I'm working on it" rather than "I'm ignoring you." The key finding is that *away* matters, not which specific direction. **[Theory]** Up-right is the conventional direction for cognitive processing (visual-constructed in NLP terms, though the neuroscience evidence for directionality is weak). **[Inference]** We use up-right (gaze_x=+0.5, gaze_y=-0.3) as a recognizable "thinking" direction. The exact direction should be validated in T3/T4 evaluation.

**Awareness indicators addressed**: Predictive cueing (gaze aversion signals processing before speech begins), gaze coherence (deliberate direction, not random wander).

---

**SPEAKING** (TTS playback active)

| Channel | Behavior |
|---|---|
| Border | White-teal (200, 240, 255), energy-reactive alpha: 0.3 + 0.7 × energy |
| LED | White-teal at 16% of border alpha |
| Gaze | Return to center (0, 0) on entry, then MCU handles via mood |
| Mood | Set by AI worker (emotion matching response content) |
| Mouth | Talking animation driven by TTS energy (0–255) at ~20 Hz |
| Flags | IDLE_WANDER=0, AUTOBLINK=1 |

**Transition into SPEAKING**: Gaze returns to center (anticipation blink, see §5.2), then talking begins. The gaze return from THINKING aversion to center functions as the predictive cue: "I'm about to speak."

**[Empirical]** Takayama et al. (2011, N=273): Applying animation principles (anticipation, follow-through) to robot motion significantly improves perceived quality of robot behavior overall. The study measures general quality ratings, not specific transition timing or gaze parameters. **[Inference]** We apply the anticipation principle specifically to gaze return before speaking as a predictive cue.

---

**ERROR** (conversation error — ASR failure, network timeout, etc.)

| Channel | Behavior |
|---|---|
| Border | Orange (255, 160, 60), flash for 100 ms then exponential decay over 700 ms |
| LED | Orange at 16% of border alpha, decays with border |
| Gaze | Quick look-away then return (gaze_x = -0.3 for 200 ms, then center) |
| Mood | Hold current; do not change mood on error |
| Flags | Inherit from previous state (preserve current wander/blink settings). On recovery, set target state defaults. |
| Duration | 800 ms total, then auto-return to IDLE or LISTENING (depending on session state) |

---

**DONE** (conversation session ending)

| Channel | Behavior |
|---|---|
| Border | Fade current color to black over 500 ms (alpha → 0) |
| LED | Fade with border |
| Gaze | Release to MCU idle wander (set IDLE_WANDER=1) |
| Mood | Fade intensity to 0.0 over 500 ms (return to neutral) |
| Flags | Restore idle defaults: IDLE_WANDER=1, AUTOBLINK=1, SPARKLE=1 |
| Duration | 500 ms, then state → IDLE |

### 4.3 Idle Behavior (D4:B)

When no conversation is active and no system overlay is shown.

| Feature | Specification | Parameter Type |
|---|---|---|
| **Breathing** | Continuous sinusoidal eye scale modulation at 1.8 rad/s | Cosmetic |
| **Auto-blink** | Random interval 2.0–5.0 s, duration 180 ms | Cosmetic |
| **Gaze wander** | New random target every 1.5–4.0 s, spring dynamics (k=0.25, d=0.65) | Cosmetic |
| **Saccade jitter** | Small random perturbations on gaze position | Cosmetic |
| **Sparkle** | Random activation p=0.05/frame, random position, white pixel | Cosmetic |
| **Mood** | Set by personality worker snapshot. Default NEUTRAL at low intensity. During extended idle, the worker may project SLEEPY or CURIOUS per PE spec §7 idle rules. Context gate (§7.3) prevents negative moods during idle. | Semantic |
| **Border** | Off | Semantic |
| **LED** | Off | Semantic |
| **Backlight** | Default brightness (200/255) | Semantic |

**Emotional idle vs cosmetic idle**: The personality worker (PE spec §7) drives idle mood shifts at 1 Hz (semantic layer), while the MCU drives visual cosmetics (breathing, blink, gaze wander, sparkle) at 30 FPS (cosmetic layer). These operate on separate channels per §3.1 and do not interact. The MCU's cosmetic animations continue regardless of which mood the worker projects.

**Over-interpretation risk**: Idle gaze wander may cause children to believe the robot is "looking at something." This is the primary over-interpretation vector for idle state.

**Gaze displacement math** (verified from `config.h` and `face_ui.cpp`):
- MAX_GAZE = 12.0 — MCU picks random wander targets in [-12, 12]
- GAZE_EYE_SHIFT = 3.0 → max eye body displacement = ±36 px
- GAZE_PUPIL_SHIFT = 8.0 → max pupil displacement = ±96 px (clamped by eye bounds)
- On a 320 px wide screen, this is significant — pupils can visibly track to corners.

**Mitigation**: Idle gaze wander is *intentionally* large enough to read as "looking around" — it creates the impression of environmental awareness that makes the face feel alive. The spring dynamics (k=0.25, d=0.65) produce smooth, unhurried motion that avoids the "darting eyes" effect of instant snaps. The bounded stochastic policy (D10:B) means wander is cosmetic, not semantic — the same wander pattern in every idle session, with no correlation to actual objects.

**[Inference]** Over-interpretation risk is real and must be measured in T4 child evaluation (Phase 4 of eval plan). If testing shows excessive over-interpretation (>20% strong attribution), the fix is to reduce MAX_GAZE or idle wander target range — a Tuning-class change that does not require architectural revision.

### 4.4 System Overlays

System overlays use Buddy's face features to communicate system states — the same expressive language the child already understands. Each mode drives eyes, mouth, eyelids, and color directly through FaceState, with a small SDF status icon overlaid in the lower-right corner for additional context.

| System Mode | Face Expression | Status Icon | Priority |
|---|---|---|---|
| BOOTING | Sleepy eyes opening → yawn → settle to neutral (~3 s) | None | Highest |
| ERROR_DISPLAY | Confused expression, slow headshake, warm orange/amber | Warning triangle (lower-right) | Highest |
| LOW_BATTERY | Heavy eyelids, periodic yawns, blue tone with brightness dim | Battery bar (lower-right, param: 0–255 fill level) | Highest |
| UPDATING | Thinking expression, gaze drifts up-right, blue-violet | Progress bar (bottom) | Highest |
| SHUTTING_DOWN | Reverse of boot — yawn, droop, eyelids close, fade to black (~2.5 s) | None | Highest |

System overlays suppress all other layers, including conversation border rendering and corner buttons. Corner button hit-testing is disabled while `SystemMode != NONE`. When a system overlay clears, the face returns to whatever tonic state was active (idle or conversation), and the border + buttons resume from their current conversation state.

---

## 5. Transition Choreography (D7:B)

**Principle**: Major transitions include anticipation micro-gestures. Minor transitions use the existing exponential tween. This addresses awareness indicator #3 (predictive cueing).

**[Empirical]** Takayama et al. (2011): Applying animation principles to robot motion improves perceived legibility. Thomas & Johnston (1981) codify "anticipation" — a preparatory motion before the main action — as one of the twelve principles of animation. **[Inference]** We implement anticipation as micro-gestures (blinks, gaze shifts) preceding major state transitions. The specific choreography timings (100 ms blink, 150 ms ramp-down, etc.) are design choices, not empirically derived values.

### 5.1 Major Transitions (Choreographed)

#### 5.1.1 Mood Switch Sequence

Triggered when the personality worker's snapshot contains a different mood than the currently displayed mood. The tick loop detects the mood change and orchestrates the visual transition. (In backstop mode — worker snapshot stale > 3000 ms — triggered when a raw AI emotion differs from the current mood.)

**Supervisor-managed sequence** (D8:C — intensity blending):

| Step | Duration | Action |
|---|---|---|
| 1. Anticipation blink | 100 ms | Trigger BLINK gesture (eyes close briefly) |
| 2. Intensity ramp-down | 150 ms | Current mood intensity 1.0 → 0.0 (linear ramp via tick_loop, ~8 SET_STATE commands at 50 Hz) |
| 3. Mood switch | 1 tick (20 ms) | Send new mood_id at intensity 0.0 |
| 4. Intensity ramp-up | 200 ms | New mood intensity 0.0 → target (linear ramp, ~10 SET_STATE commands) |

**Total duration**: ~470 ms

**Timing budget**: This sequence adds ~470 ms of latency to mood changes. **[Empirical]** Denham (1986) found that children use context + face together for emotion recognition; face alone is insufficient for nuanced recognition. **[Inference]** During conversation, 470 ms is acceptable because AI-chosen emotions arrive during SPEAKING phase where TTS audio provides the contextual bridge. The child hears the robot's tone before seeing the full mood shift, which should aid recognition. Must be validated in T3 developer review.

**Interrupt behavior**: If a new mood arrives during an active transition, the current transition is abandoned at its current intensity, and a new sequence starts from the current intensity value. No "melting face" — the ramp always moves toward a valid mood.

#### 5.1.2 Conversation Phase Transitions

Implemented in `ConvTransitionChoreographer` (sim: `tools/face_sim_v3/state/conv_choreographer.py`, supervisor: `supervisor/core/conv_choreographer.py`). The choreographer fires timed actions on state transitions and does not mutate face state directly — tick_loop reads outputs.

| Transition | Choreography | Duration | Implementation |
|---|---|---|---|
| IDLE → ATTENTION | Border inward sweep + gaze snap to center | 400 ms | MCU border sweep + conv_state gaze override |
| ATTENTION → LISTENING | Border color blend (cyan → teal) + alpha settles to breathing | 200 ms (blended at BLEND_RATE=8.0/s) | MCU border BLEND_RATE |
| LISTENING → THINKING | Gaze ramp (ease-out, center → up-right) + border color shift + orbit dots start | 300 ms | Choreographer `_GazeRamp` (TRANS_LT_GAZE_RAMP_MS) + MCU spring |
| THINKING → SPEAKING | Anticipation blink + gaze ramp (ease-out, up-right → center, 50 ms delay) + border color shift | 350 ms | Choreographer blink gesture + `_GazeRamp` (TRANS_TS_GAZE_RAMP_MS). Double-blink prevention: choreographer blink suppresses MoodSequencer anticipation blink |
| SPEAKING → LISTENING | Re-engagement NOD (100 ms delay) | 450 ms | Choreographer nod gesture (TRANS_SL_NOD_DELAY_MS). Backchannel NOD suppressed while choreographer active |
| SPEAKING → DONE | Mood nudge to NEUTRAL @ 0.0 + mood pipeline suppressed (500 ms) + border fade | 500 ms | Choreographer mood_nudge + suppress_mood_pipeline (TRANS_SD_SUPPRESS_MS). MoodSequencer handles 470 ms ramp |
| Any → ERROR | Border flash (immediate) + gaze micro-aversion (200 ms) | 800 ms total | MCU border flash + conv_state micro-aversion override |

**Gaze priority chain** (tick_loop): choreographer ramp > conv_state static override > default.

**Interrupt behavior**: A new state transition cancels any active choreography sequence. The `on_transition()` method resets all state and loads the new transition's actions.

### 5.2 Minor Transitions (Tween)

These use the existing MCU exponential interpolation. No anticipation frames.

| Parameter | Tween Speed | Settle Time (~95%) |
|---|:---:|:---:|
| Gaze X/Y | Spring k=0.25, d=0.65 | ~200–300 ms |
| Eyelid top | 0.6 (rising) / 0.4 (falling) | ~100–150 ms |
| Eyelid bottom | 0.3 | ~150 ms |
| Eyelid slope | 0.3 | ~150 ms |
| Eye scale | 0.2 | ~250 ms |
| Eye openness | 0.4 | ~120 ms |
| Mouth curve | 0.2 | ~250 ms |
| Mouth open | 0.4 | ~120 ms |
| Mouth width | 0.2 | ~250 ms |
| Mouth wave | 0.1 | ~400 ms |

*Settle times are approximate at 30 FPS. Tween factor f applied per frame: after n frames, remaining distance = (1-f)^n.*

---

## 6. Timing Rules

### 6.1 Latency Budgets

| Metric | Budget | Rationale |
|---|---|---|
| Wake word → first visual change | < 200 ms | Must feel "immediate." **[Theory]** Clark (1996) discusses grounding in communication — listeners expect timely acknowledgment of communicative acts. **[Inference]** The 200–300 ms perceptual threshold for "immediate" causal attribution is drawn from general psychophysics (Exner, 1875; Pöppel, 2009), not Clark specifically. We adopt < 200 ms as our target. |
| PTT press → first visual change | < 100 ms | Button press has stronger immediacy expectation than voice. |
| End-of-utterance → THINKING visual | < 300 ms | Child should see the robot "start thinking" before silence feels awkward. |
| THINKING → SPEAKING visual | < 100 ms after TTS audio begins | Gaze return and border shift must lead or coincide with first audio frame. |
| Mood command → visible change begins | < 50 ms | MCU response time (1–2 render frames). |

### 6.2 Hold Times

Minimum duration an expression must be displayed before the next transition is permitted.

| Expression Type | Minimum Hold | Rationale |
|---|:---:|---|
| Any mood | 500 ms | **[Empirical]** Widen & Russell (2003): Children categorize facial expressions with high accuracy, but the study measures categorization, not minimum display duration. **[Inference]** We set 500 ms as the minimum hold to ensure the expression is perceptible and not subliminal. Must be validated in T4 evaluation. |
| Conversation state border | 300 ms | Border is peripheral; needs less hold time. But transitions faster than 300 ms cause flicker. **[Inference]** |
| Gesture | Full gesture duration | Gestures are self-timed (80 ms – 10 s). Never interrupt mid-gesture. |
| Negative mood | See §7 (guardrails) | Minimum 500 ms, maximum per-mood. |

### 6.3 Talking Animation Timing

| Parameter | Value | Source |
|---|---|---|
| Energy update rate | ~20 Hz (from TTS worker) | `tts_worker.py` LipSyncTracker |
| MCU talking timeout | 450 ms | `face_ui.cpp:25` — if no SET_TALKING received within 450 ms, MCU auto-stops talking animation |
| Mouth wave frequency | 8.0 rad/s phase advance | `face_state.cpp` mouth render |
| Mouth wave spatial frequency | 12.0 cycles across width | `face_ui.cpp` render_mouth |

**Prosody selection**: The emotion tag used for TTS prosody (voice pitch, speed, emphasis) is derived from the personality worker's projected mood (PE spec §11.5), not from the face communication layer. This spec covers only the visual lip sync mechanism.

---

## 7. Negative Affect Guardrails (D2:B)

**Framing**: As a caretaker/guide, the robot uses negative emotions to validate the child's feelings during conversation ("I understand that's scary") but never displays sustained distress. Kahn et al. (2012) demonstrates that children attribute genuine emotional states to robots — prolonged negative affect may cause real concern in 4–6 year olds. **[Empirical]**

**Operational definition of "destabilizing"**: The child exhibits distress behaviors — crying, flinching, backing away, asking parent for help — or reports negative feelings attributed to the robot's expression (not to conversational content). The guardrails below are calibrated to prevent this by: (a) limiting duration so negative affect is always brief, (b) capping intensity so expressions read as "mild concern" not "real distress," (c) mandatory recovery so the face always returns to neutral/positive.

**Distinguishing expression from content**: The robot may *discuss* sad or scary topics (conversational content) while displaying mild empathetic affect. The face should not independently produce distress beyond what the conversation warrants. "Allowed to mirror the child" is explicitly scoped: the AI may choose SAD to empathize with a child's sadness, but the intensity cap ensures the robot looks "understanding" not "distraught."

### 7.1 Per-Mood Guardrails

| Mood | Max Duration | Anticipation Required | Recovery Target | Recovery Time |
|---|:---:|:-----:|:---:|:---:|
| SAD | 4.0 s | Yes (blink) | NEUTRAL @ 0.0 | 500 ms ramp-down |
| SCARED | 2.0 s | Yes (blink) | NEUTRAL @ 0.0 | 300 ms ramp-down |
| ANGRY | 2.0 s | Yes (blink) | NEUTRAL @ 0.0 | 300 ms ramp-down |

For SURPRISED (Neutral class, high-arousal safety), see §7.4.

**Primary enforcement**: The personality worker (PE spec §9) tracks how long the projected mood has been in a negative state. When the duration cap is exceeded, a recovery impulse toward baseline is injected, pulling affect toward NEUTRAL. The worker's snapshot, consumed by the tick loop, reflects this recovery automatically.

**Safety backstop**: If the personality worker's snapshot is stale (age > 3000 ms, indicating the worker is dead or hung), the tick loop enforces the same duration caps directly. This prevents a failed worker from leaving a negative mood stuck on the face. The backstop uses the same durations and intensity caps as the primary enforcement.

Under normal operation, only the personality worker enforces. The tick loop backstop is a safety net, not a parallel enforcement path.

**AI override**: If the AI sends a new (different) mood before the guardrail timer expires, the new mood is accepted (via the personality worker's integrator) and the timer resets. This allows the AI to sequence emotions naturally (e.g., SAD → NEUTRAL → HAPPY) without the guardrail interrupting.

### 7.2 Intensity Limits for Negative Moods

In the caretaker role, negative moods are displayed at reduced intensity to soften their visual impact:

| Mood | Max Intensity | Rationale |
|---|:---:|---|
| SAD | 0.7 | Recognizable but not overwhelming. Reduced lid droop + mouth curve. |
| SCARED | 0.6 | Wide eyes moderated. Mouth open reduced. |
| ANGRY | 0.5 | Strongest restriction. Furrowed brows at half-strength read as "concerned" rather than "furious." |

For SURPRISED intensity cap (0.8), see §7.4.

If the AI sends intensity above the cap, the personality worker clamps it via the affect vector integrator. In backstop mode (stale snapshot), the tick loop clamps it directly.

### 7.3 Context Gate

Outside active conversation (no session in progress), negative moods (SAD, SCARED, ANGRY) are **blocked entirely**.

**Primary enforcement**: The personality worker's context gate (PE spec §9.2) prevents negative mood projection outside active conversation. If the affect vector decays through negative territory after conversation ends, the context gate overrides the projection to NEUTRAL before the snapshot reaches the tick loop.

**Safety backstop**: If the personality worker snapshot is stale (age > 3000 ms) and the tick loop falls back to raw AI emotion passthrough (PE spec §11.3), the tick loop applies the same context gate: it rejects negative moods when `conversation_active == False`.

SURPRISED is not context-gated (Neutral class). It may be used in any context, subject to the startle reflex safety cap (§7.4).

### 7.4 Startle Reflex Safety (SURPRISED)

SURPRISED is classified as Neutral (§4.1.1) — not Negative — but its high arousal (+0.80 in VA space) warrants a duration and intensity cap to prevent sustained startle:

| Mood | Max Duration | Max Intensity | Recovery Target | Recovery Time |
|---|:---:|:---:|:---:|:---:|
| SURPRISED | 3.0 s | 0.8 | NEUTRAL @ 0.0 | 400 ms ramp-down |

This rule applies in all contexts (conversation and idle). Enforcement follows the same tiered model as negative mood guardrails: personality worker primary (PE spec §9.1), tick loop backstop.

---

## 8. Gesture Catalog

Gestures are phasic — they overlay the current tonic state and expire after their duration.

| GestureId | Default Duration | Use Context | Semantic Weight |
|---|:---:|---|:---:|
| BLINK | 180 ms | Transition choreography, natural rhythm | Cosmetic |
| WINK_L | 200 ms | Playful acknowledgment | Semantic |
| WINK_R | 200 ms | Playful acknowledgment | Semantic |
| NOD | 350 ms | Agreement, understanding | Semantic |
| HEADSHAKE | 350 ms | Disagreement, negation | Semantic |
| LAUGH | 500 ms | Joy, humor response | Semantic |
| CONFUSED | 500 ms | Uncertainty, didn't understand | Semantic |
| WIGGLE | 600 ms | Playful energy, excitement | Semantic |
| SURPRISE | 800 ms | Startle, amazement | Semantic |
| HEART | 2.0 s | Affection (solid eye heart shape) | Semantic |
| X_EYES | 2.5 s | Comedic "dizzy" / overload | Semantic |
| SLEEPY | 3.0 s | Tired, winding down | Semantic |
| RAGE | 3.0 s | Comedic anger (fire effect) | Semantic |

**Semantic vs cosmetic**: BLINK is the only cosmetic gesture (used for transitions and auto-blink). All others carry meaning and should only be triggered by AI/planner commands, not autonomously.

**Guardrail note**: RAGE and X_EYES trigger special visual effects (fire particles, X-shaped eyes) that override normal rendering. Per the caretaker role, these should be used sparingly and only in clearly playful/comedic conversational contexts. The AI system prompt should restrict their use.

---

## 9. Protocol Mapping

### 9.1 Existing Commands (Sufficient)

| Behavior | Command | Payload | Notes |
|---|---|---|---|
| Set emotion + intensity + gaze | SET_STATE (0x20) | mood_id, intensity_u8, gaze_x_i8, gaze_y_i8, brightness_u8 | Gaze override for LISTENING sent here |
| Trigger gesture | GESTURE (0x21) | gesture_id, duration_ms | Anticipation blinks use this |
| System overlay | SET_SYSTEM (0x22) | mode, phase, param | Unchanged |
| Talking animation | SET_TALKING (0x23) | talking, energy | Unchanged |
| Feature flags | SET_FLAGS (0x24) | flags bitfield | IDLE_WANDER control for gaze lock |

### 9.2 New Command Required: SET_CONV_STATE (0x25)

The conversation border is currently sim-only (`conv_border.py`). Porting it to firmware requires a new command.

**Proposed payload**:

```
struct __attribute__((packed)) FaceSetConvStatePayload {
    uint8_t conv_state;  // ConvState enum (0–7)
};
```

**Byte layout** (1 byte):
- Offset 0: conv_state (uint8_t) — maps to ConvState enum

**Energy for SPEAKING border**: The MCU border renderer reads audio energy from `fs.talking_energy`, which is already latched by the SET_TALKING (0x23) command at ~20 Hz. During SPEAKING, border alpha = 0.3 + 0.7 × fs.talking_energy. This avoids duplicating the energy field — SET_TALKING is the single source of truth for audio energy.

**ConvState enum** (firmware side):

```cpp
enum class ConvState : uint8_t {
    IDLE      = 0,
    ATTENTION = 1,
    LISTENING = 2,
    PTT       = 3,
    THINKING  = 4,
    SPEAKING  = 5,
    ERROR     = 6,
    DONE      = 7,
};
```

**MCU responsibilities** (border rendering moves to firmware):
- Maintain border state machine (color, alpha, animation timers)
- Render border frame (4 px) + glow (3 px) via SDF
- Render orbit dots for THINKING state
- Blend border alpha based on state (breathing, pulse, energy-reactive)
- Set LED color = border color × 0.16

**Supervisor responsibilities**:
- Track conversation state and send SET_CONV_STATE on **state transitions only** (no per-tick energy — border reads `fs.talking_energy` from SET_TALKING)
- Continue sending SET_TALKING with energy at ~20 Hz during SPEAKING (already implemented)
- Manage gaze overrides via SET_STATE (gaze_x, gaze_y fields)
- Manage flag overrides via SET_FLAGS (IDLE_WANDER bit)

### 9.3 Flag Usage Per Conversation State

| Conv State | IDLE_WANDER | AUTOBLINK | SPARKLE | Notes |
|---|:---:|:---:|:---:|---|
| IDLE | 1 | 1 | 1 | All defaults |
| ATTENTION | 0 | 1 | 1 | Wander off for gaze snap |
| LISTENING | 0 | 1 | 1 | Wander off for center lock |
| PTT | 0 | 1 | 1 | Same as LISTENING |
| THINKING | 0 | 1 | 0 | Wander off; sparkle off (cleaner thinking visual) |
| SPEAKING | 0 | 1 | 1 | Wander off during speech |
| ERROR | — | — | — | No flag change |
| DONE | 1 | 1 | 1 | Restore defaults |

### 9.4 Link Assumptions

The supervisor communicates with the face MCU over USB-CDC serial (COBS-encoded binary packets with CRC16-CCITT).

**Reliability**: USB-CDC serial is reliable and ordered — no packet loss, no reordering. The COBS framing + CRC provides error detection; corrupted packets are discarded by the receiver.

**Throughput**: During SPEAKING (peak load), supervisor sends up to 3 command types per tick: SET_STATE (5 bytes payload), SET_TALKING (2 bytes payload), SET_CONV_STATE (1 byte payload). With COBS overhead (~2 bytes) + CRC (2 bytes) + delimiter (1 byte) per packet, total is ~39 bytes/tick × 50 Hz = ~1950 bytes/s — well within USB full-speed bandwidth.

**Timing**: MCU applies last-value-wins per command type per render frame (33 ms). If a packet is delayed by >1 tick (20 ms), the next tick's packet supersedes it. No accumulation or queuing on the MCU side — only the most recent value of each command type is rendered.

**Mood transition bandwidth**: The mood switch choreography (§5.1.1) sends ~18 SET_STATE packets over 350 ms (intensity ramp). This is well within link capacity and each packet supersedes the previous if delayed.

### 9.5 Touch Semantics for Conversation Control

**PTT button** (FaceButtonId.PTT): Tap-toggle — each tap in the PTT zone inverts the listening state. First tap → ATTENTION → PTT (listening active). Second tap → THINKING (listening ended). Toggle fires on touch release within the same hit zone. Already defined in protocol.

**ACTION button** (FaceButtonId.ACTION): Context-gated behavior:
- **During active conversation** (`conversation_active == True`): CLICK → cancel session (→ DONE state). Provides a way to abort a conversation that's stuck or unwanted.
- **Outside conversation** (`conversation_active == False`): CLICK → greet routine (current behavior, `tick_loop.py:331-337`).

**Implementation note**: Requires modifying the ACTION button handler in `tick_loop.py` to check `conversation_active` before deciding greet vs cancel.

**Soft buttons**: Corner button hit zones are flush with screen edges (Fitts's Law — edge targets benefit from infinite depth). Constants defined in `BTN_CORNER_*` (parity-checked between sim and firmware):
- PTT: bottom-left, 60×46 px zone — x ∈ [0, 60], y ∈ [194, 240], icon center (30, 217)
- Cancel: bottom-right, 60×46 px zone — x ∈ [260, 320], y ∈ [194, 240], icon center (290, 217)

Corner buttons are hidden and hit-testing is disabled during system overlays (§4.4).

### 9.6 Supervisor Tick Loop Integration

The conversation state machine runs in `tick_loop` at 50 Hz. On each tick:

1. **Check for conversation events** (wake word, end-of-utterance, TTS start/finish, errors)
2. **Advance conversation state** based on events
3. **On state change**:
   a. Send SET_CONV_STATE with new state
   b. Send SET_FLAGS with updated flag byte
   c. If entering LISTENING/ATTENTION: send SET_STATE with gaze (0, 0)
   d. If entering THINKING: send SET_STATE with gaze (0.5, -0.3) and mood THINKING @ 0.5
   e. If entering SPEAKING: send SET_STATE with gaze (0, 0), initiate anticipation blink
   f. If entering DONE: begin mood intensity ramp-down over 500 ms
4. **During SPEAKING**: TTS energy continues flowing via SET_TALKING at ~20 Hz (already implemented). MCU border reads `fs.talking_energy` directly — no additional energy commands needed.
5. **Mood transition choreography**: if the personality worker's snapshot contains a new mood different from the currently displayed mood, run §5.1.1 sequence via tick-by-tick intensity ramping. The tick loop does not interpret AI emotions directly — it reads the worker's projected mood from the snapshot. (In backstop mode — stale snapshot — falls back to raw AI emotion.)

---

## 10. Sim/MCU Divergence Audit (D9:C)

One-time audit. After resolution, sim is the design authoring surface. MCU must match within tolerance. Divergence is a CI-detectable error.

### 10.1 Known Divergences and Resolutions

| Parameter | Sim Value | MCU Value | Resolution | Rationale |
|---|---|---|:---:|---|
| Blink interval | 3.0–7.0 s | 2.0–5.0 s | **MCU** (2.0–5.0 s) | More natural blink rate. Human adult rate is ~3–4 s average; children blink faster. |
| Idle gaze interval | 1.0–3.0 s | 1.5–4.0 s | **MCU** (1.5–4.0 s) | Slower wander feels more intentional, less jittery. |
| Background color | (10, 10, 14) | (0, 0, 0) | **MCU** (0, 0, 0) | Pure black maximizes contrast on ILI9341 TN panel. Sim's dark gray was aesthetic choice for pygame. |
| THINKING color | Falls through to NEUTRAL | (80, 135, 220) | **MCU** (80, 135, 220) | Explicit color is correct — THINKING should be visually distinct. Sim bug. |
| Talking phase speed | Variable | Fixed | **MCU** (fixed) | Consistent wave speed simplifies debugging and matches TTS energy rhythm. |

### 10.2 Enforcement Policy

After this audit, all parameter values are defined in this spec (§4, §6). Going forward:

1. **Sim is the design authoring surface** — new values are prototyped in sim first
2. **MCU must match within tolerance** — facial parameter targets must be identical; timing may differ by ±1 frame (33 ms) due to frame rate differences
3. **CI check**: A script compares sim constants (`face_state_v2.py`) against MCU constants (`face_state.cpp`, `config.h`) and fails on divergence
4. **Exception process**: If hardware testing reveals a value that must differ (e.g., display gamma), the exception is documented in this spec with rationale

---

## 11. Priority Layer Composition

Updated priority stack incorporating conversation state:

```
┌─────────────────────────────────────────────────┐
│ Layer 0: System Overlay                         │  BOOTING / ERROR / LOW_BATTERY / UPDATING / SHUTTING_DOWN
│          (full screen takeover)                  │  Source: robot.mode
├─────────────────────────────────────────────────┤
│ Layer 1: Talking Animation                      │  Lip sync (mouth only)
│          (mouth override)                        │  Source: TTS worker energy
├─────────────────────────────────────────────────┤
│ Layer 2: Conversation State                     │  Border + LED + gaze override + mood hints
│          (multimodal, D3:C)                     │  Source: tick_loop state machine
├─────────────────────────────────────────────────┤
│ Layer 3: Emotion                                │  Eyes + mouth + face color
│          (personality worker snapshot)           │  Source: personality worker → tick loop
├─────────────────────────────────────────────────┤
│ Layer 4: Idle                                   │  Neutral + breathing + blink + gaze wander + sparkle
│          (MCU autonomous)                        │  Source: MCU defaults
└─────────────────────────────────────────────────┘
```

**Key changes from current**: Layer 2 (Conversation State) is new. It owns the border, LED, and gaze-during-LISTENING. It does *not* own eyes/mouth — those remain under the Emotion layer. The two layers coexist on separate channels per §3.1. Layer 3 source updated: the personality worker is now the single source of emotional truth (PE spec §11.1). AI worker and planner emotions are processed as impulses by the personality worker, which projects a final mood + intensity consumed by the tick loop.

**Collision resolution**:
- If Layer 2 sets gaze (LISTENING center lock) while Layer 3 sets a mood, the gaze from Layer 2 wins. Mood still controls eyes/mouth/color.
- If Layer 1 (talking) is active while Layer 3 (emotion) sets a mood, talking controls the mouth. Emotion controls eyes and color.
- If Layer 0 (system) is active, everything else is suppressed.

---

## 12. Conversation State Machine — Full Specification

### 12.1 State Transition Table

| Current State | Event | Next State | Actions |
|---|---|---|---|
| IDLE | wake_word_detected | ATTENTION | Send CONV_STATE(ATTENTION), SET_FLAGS(wander=0), SET_STATE(gaze=center) |
| IDLE | ptt_toggled_on | ATTENTION | Same as wake word. PTT flag set → advance to PTT after ATTENTION completes. If toggled off during ATTENTION → auto-advance to LISTENING. |
| ATTENTION | 400 ms elapsed (PTT not active) | LISTENING | Send CONV_STATE(LISTENING), SET_STATE(gaze=center) |
| ATTENTION | 400 ms elapsed (PTT active) | PTT | Send CONV_STATE(PTT) — tap-to-talk active, enter PTT listening |
| ATTENTION | ptt_toggled_on (during ATTENTION) | PTT | Send CONV_STATE(PTT) — late tap also enters PTT |
| LISTENING | vad_end_of_utterance | THINKING | Send CONV_STATE(THINKING), SET_STATE(gaze=aversion, mood=THINKING@0.5) |
| LISTENING | session_cancelled | DONE | Send CONV_STATE(DONE) |
| PTT | ptt_toggled_off | THINKING | Send CONV_STATE(THINKING), SET_STATE(gaze=aversion, mood=THINKING@0.5) |
| PTT | session_cancelled | DONE | Send CONV_STATE(DONE) |
| THINKING | tts_started | SPEAKING | Anticipation blink, send CONV_STATE(SPEAKING), SET_STATE(gaze=center) |
| THINKING | ai_error | ERROR | Send CONV_STATE(ERROR) |
| THINKING | 30 s timeout | ERROR | Send CONV_STATE(ERROR) — AI hung |
| SPEAKING | tts_finished | LISTENING or DONE | If multi-turn: → LISTENING. If session done: → DONE |
| SPEAKING | tts_cancelled | DONE | Send CONV_STATE(DONE) |
| ERROR | 800 ms elapsed | IDLE or LISTENING | If session still active: → LISTENING. Otherwise: → IDLE |
| DONE | 500 ms elapsed | IDLE | Restore idle flags, clear conversation state |

### 12.2 Multi-Turn Handling

A conversation session may include multiple turns (child speaks → robot responds → child speaks again). The state machine loops:

```
LISTENING → THINKING → SPEAKING → LISTENING → THINKING → SPEAKING → ... → DONE
```

Session end is signaled by `AI_CONVERSATION_DONE` event. The SPEAKING → DONE transition only fires when the AI signals the session is complete *and* TTS has finished.

### 12.3 Edge Cases

| Scenario | Behavior |
|---|---|
| Wake word during SPEAKING | Ignored — robot finishes its turn. New wake word after DONE/IDLE starts fresh session. |
| PTT during SPEAKING | Session interrupts. Stop TTS, → LISTENING (PTT variant). |
| Touch cancel during any state | → DONE immediately. Graceful shutdown. |
| Network loss during THINKING | 30 s timeout → ERROR → IDLE. |
| AI emotion during LISTENING | Integrated into personality worker's affect vector immediately, but not displayed on face until SPEAKING entry (§2.3 suppress-then-read). Face stays attentive neutral during LISTENING. On SPEAKING entry, tick loop reads current snapshot (which already reflects the integrated emotion). |
| Rapid mood commands during SPEAKING | Each triggers mood switch sequence (§5.1.1). Minimum hold (500 ms) enforced — second mood queued if too fast. |

---

## 13. Summary of Awareness Indicators Coverage

Cross-reference against the 5 awareness indicators from [S1-C1]:

| Indicator | How This Spec Addresses It | Measured By |
|---|---|---|
| **Temporal correlation** | Wake word → ATTENTION in <200 ms. PTT → visual in <100 ms. Every conversation event has a corresponding visual change. | Response latency (§6.1) |
| **Gaze coherence** | LISTENING = center lock. THINKING = deliberate aversion. SPEAKING = return to center. No random wander during conversation. | Gaze variance per state (automated) |
| **Predictive cueing** | Anticipation blink before mood switch. Gaze return before speaking. Border color shift before state change. | Presence of anticipation frame (binary per transition) |
| **State continuity** | 500 ms minimum hold for moods. 300 ms minimum hold for border states. No single-frame flickers. | Hold time compliance (automated) |
| **Acknowledgment** | ATTENTION state with border flash + gaze snap within perceptual threshold of wake word/PTT. | Time-to-first-visual-change (instrumented) |

---

## 14. Summary of Randomness Failure Mode Fixes

Cross-reference against the 5 randomness failure modes from [S1-C1]:

| Failure Mode | Fix in This Spec |
|---|---|
| **Uncorrelated gaze during conversation** | §4.2 — IDLE_WANDER=0 during all conversation states. Gaze is supervisor-controlled (center lock or deliberate aversion). |
| **Unexplained emotion transitions** | §5.1.1 — Mood switch sequence with anticipation blink + intensity ramp. Changes feel intentional. §6.2 — 500 ms minimum hold prevents flickers. |
| **No THINKING visual signal** | §4.2.2 THINKING state — blue-violet orbit border + gaze aversion + THINKING mood. Processing delay is now visible and intentional. |
| **Talking stops before speech ends** | §6.3 — MCU talking timeout is 450 ms. Supervisor must send SET_TALKING updates at ≥2 Hz during TTS playback. Existing bug to fix in implementation. |
| **No wake word acknowledgment** | §4.2.2 ATTENTION state — border flash + gaze snap within <200 ms of detection. |

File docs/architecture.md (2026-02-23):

# Architecture

## System Topology

```
┌──────────────────────────────────────────────────────────┐
│ On Robot                                                 │
│                                                          │
│  ┌────────────────────────────────────────────────────┐  │
│  │ Raspberry Pi 5 — Supervisor                        │  │
│  │                                                    │  │
│  │  50 Hz tick loop:                                  │  │
│  │    read telemetry → state machine → safety         │  │
│  │    → mood sequencer → conv state → send commands   │  │
│  │    → broadcast telemetry to dashboard              │  │
│  │                                                    │  │
│  │  Workers (separate OS processes):                  │  │
│  │    TTS, Vision, AI/Planner, Ear (wake word + VAD)  │  │
│  │                                                    │  │
│  │  HTTP API (:8080)  WebSocket (:8080/ws)            │  │
│  └──────┬──────────────────────┬──────────────────────┘  │
│         │ USB serial (COBS)    │ USB serial (COBS)       │
│  ┌──────▼──────┐        ┌─────▼───────┐                 │
│  │ Reflex MCU  │        │  Face MCU   │                 │
│  │ ESP32-S3    │        │  ESP32-S3   │                 │
│  │             │        │             │                 │
│  │ Motors, PID │        │ 320×240 TFT │                 │
│  │ Encoders    │        │ Face render │                 │
│  │ IMU (BMI270)│        │ Touch/Btns  │                 │
│  │ Ultrasonic  │        │ Border/LED  │                 │
│  │ Safety      │        │             │                 │
│  └─────────────┘        └─────────────┘                 │
└──────────────────────────────────────────────────────────┘
         │
         │ HTTP (LAN, optional)
         │
┌────────▼────────────────────────────────┐
│ AI Server (3090 Ti PC, off-robot)       │
│                                         │
│ FastAPI planner server (:8100)          │
│ LLM: Qwen3-8B-AWQ via vLLM             │
│ TTS: Orpheus (vLLM) + espeak fallback   │
│ STT: faster-whisper (CPU)               │
│ POST /plan  WS /converse  POST /tts     │
└─────────────────────────────────────────┘
```

## Locked Decisions

- 2× ESP32-S3: Face MCU (display + touch) and Reflex MCU (motors + sensors + safety)
- Raspberry Pi 5 runs Python supervisor at 50 Hz
- AI planner services run off-robot on 3090 Ti server via LAN
- Battery: 2S LiPo with separate dirty motor rail and clean regulated 5V rail
- Reflexes are local and deterministic; planner is remote and optional

## Supervisor Architecture

### Tick Loop (50 Hz)

The tick loop is the central orchestrator. Each tick:

1. **Read**: Poll telemetry from both MCUs (non-blocking)
2. **State machine**: Evaluate transitions (BOOT → IDLE → TELEOP/WANDER → ERROR)
3. **Safety policies**: Apply 7-layer defense-in-depth (mode gate, fault gate, disconnect guard, range scaling, stale range fallback, vision confidence, stale vision timeout)
4. **Conversation state**: Advance ConvStateTracker (8 states: IDLE → ATTENTION → LISTENING → PTT → THINKING → SPEAKING → ERROR → DONE)
5. **Mood sequencer**: Execute 4-phase choreography (anticipation blink → ramp-down → switch → ramp-up, ~470ms)
6. **Guardrails**: Enforce negative affect limits (context gate, intensity caps, duration caps)
7. **Transition choreographer**: Gaze ramps, anticipation blinks, re-engagement nods on conversation phase changes
8. **Send commands**: Emit SET_STATE, GESTURE, SET_TALKING, SET_CONV_STATE, SET_FLAGS to Face MCU; SET_TWIST to Reflex MCU
9. **Broadcast**: Stream telemetry to dashboard via WebSocket (20 Hz)

### Worker Process Model

Workers run as separate OS processes communicating via NDJSON over pipes:

| Worker | Process | Rate | Role |
|---|---|---|---|
| TTS | Separate | Event-driven | Audio playback, lip sync energy (RMS → 0-255) |
| Vision | Separate | 10-20 Hz | Camera capture, object detection, ball tracking |
| AI | Separate | Event-driven | Planner client (POST /plan), conversation (WS /converse) |
| Ear | Separate | Continuous | Wake word detection (openWakeWord), VAD (Silero) |

Worker crashes don't bring down the tick loop. Workers communicate via typed events on the event bus.

### State Machine

```
BOOT → IDLE → TELEOP / WANDER → ERROR
  │      │                          │
  │      └──── set_mode ────────────│
  │                                 │
  └──── auto (reflex connects) ─────┘ ← clear_error (when healthy)
```

- **BOOT → IDLE**: Automatic when Reflex MCU connects with no faults
- **IDLE → TELEOP/WANDER**: Via `set_mode` command
- **Any → ERROR**: On disconnect, ESTOP, TILT, or BROWNOUT
- **ERROR → IDLE**: Via `clear_error()` when Reflex is healthy

## Communication Protocol

Binary packets over USB serial with COBS framing:

**v1 envelope**: `[type:u8][seq:u8][payload:N][crc16:u16-LE]`

**v2 envelope** (negotiated): `[type:u8][seq:u32-LE][t_src_us:u64-LE][payload:N][crc16:u16-LE]`

CRC16-CCITT (polynomial 0x1021, init 0xFFFF). Protocol version negotiated via SET_PROTOCOL_VERSION (0x07) / PROTOCOL_VERSION_ACK (0x87).

Auto-reconnect with exponential backoff (0.5s–5s). See `docs/protocols.md` for full packet definitions.

### Face MCU Commands

| ID | Command | Pattern | Purpose |
|----|---|---|---|
| 0x20 | SET_STATE | Last-value-wins | Mood, intensity, gaze, brightness |
| 0x21 | GESTURE | FIFO queue (cap 16) | One-shot animations |
| 0x22 | SET_SYSTEM | Last-value-wins | System overlays (boot, error, battery) |
| 0x23 | SET_TALKING | Last-value-wins | Lip sync (talking flag + energy) |
| 0x24 | SET_FLAGS | Last-value-wins | Feature toggles (blink, wander, sparkle) |
| 0x25 | SET_CONV_STATE | Last-value-wins | Conversation border state |

### Face MCU Telemetry

| ID | Telemetry | Rate |
|----|---|---|
| 0x90 | FACE_STATUS | 20 Hz |
| 0x91 | TOUCH_EVENT | On change |
| 0x92 | BUTTON_EVENT | On change |
| 0x93 | HEARTBEAT | 1 Hz |

## Safety Architecture (Defense in Depth)

Safety enforcement at two levels:

**MCU-level (Reflex)**: Acceleration limits, command TTL (400ms timeout), hard stop on ESTOP/TILT/STALL, watchdog.

**Supervisor-level**: 7 policies applied every tick:
1. Mode gate — no motion outside TELEOP/WANDER
2. Fault gate — any fault → zero twist
3. Reflex disconnect → zero twist
4. Ultrasonic range scaling (hard stop at 250mm, 50% at 500mm)
5. Stale range fallback (50% cap)
6. Vision confidence scaling
7. Stale vision timeout (500ms)

## Face Rendering Pipeline

**Face MCU** (ESP32-S3 + ILI9341 320×240 SPI):
- 30 FPS render loop on core 0
- SDF-based eye/mouth rasterization with spring gaze, idle wander, micro-saccades, breathing
- 13 moods with per-mood eye scale, color, expression targets
- 13 gestures (one-shot FIFO queue)
- Conversation border renderer (SDF frame + glow, 8 state animations)
- Corner button zones (pixel-rendered MIC + X_MARK icons, touch hit-testing)
- System overlays (boot, error, low battery, updating, shutdown)
- Effects: sparkle, fire particles (rage), afterglow blending

**Design authoring surface**: Face Sim V3 (`tools/face_sim_v3/`, ~2600 lines) is the canonical design tool. CI parity check enforces constant alignment between sim and firmware (196/196 checks).

## Personality Engine (Planned)

Spec: `specs/personality-engine-spec-stage2.md`

- **PersonalityWorker**: Dedicated BaseWorker on Pi 5 (1 Hz tick + event-triggered)
- **Continuous affect vector**: (valence, arousal) with decaying integrator
- **13 mood anchors** in VA space with asymmetric hysteresis projection
- **Layer 0**: Deterministic rules (no server required)
- **Layer 1**: LLM-enhanced via Qwen3-8B-AWQ on server
- **Single source of emotional truth**: Personality worker is final authority on face + TTS prosody
- **Memory**: Local-only JSON, 5 decay tiers, COPPA compliant

## Deterministic Telemetry

All MCU packets carry monotonic timestamps (`t_src_us`) and sequence numbers. Pi receives with `t_pi_rx_ns`. Clock sync via TIME_SYNC_REQ/RESP (min-RTT offset, drift tracking). Raw binary logging for deterministic replay.

## Open Questions

- Final battery pack choice (2S LiPo vs welded 2S 18650 pack with BMS)
- Motor voltage strategy (raw 2S capped PWM vs regulated motor rail)

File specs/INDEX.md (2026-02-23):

# Specifications Index

Quick reference for navigating the spec documents. Use section links for targeted reading.

## Face Communication

### [face-communication-spec-stage1.md](face-communication-spec-stage1.md)
Research foundations. Defines the research approach (3 buckets), verified system snapshot, and design methodology. Start here for understanding the research basis.

### [face-communication-spec-stage2.md](face-communication-spec-stage2.md)
**Full implementation-ready spec** (~1340 lines). The primary reference for face communication work.
- §1-2: Intent taxonomy, personality profile, channel allocation
- §3: Layer interaction rules (emotion suppression, queue-during/apply-on-speaking)
- §4: Visual grammar — 13 moods, 13 gestures, eye scale, color, expression targets
- §5: Mood transition choreography (blink → ramp-down → switch → ramp-up)
- §6: Latency targets (frame budget, command-to-pixel)
- §7: Negative affect guardrails (context gate, intensity caps, duration caps, auto-recovery)
- §8: Conversation states (8 states, transitions, auto-timeouts)
- §9: Protocol extensions (SET_CONV_STATE 0x25, SET_FLAGS 0x24)
- §12: Full conversation state machine with transition choreography

### [face-communication-eval-plan.md](face-communication-eval-plan.md)
Testing & evaluation framework with 4 tiers:
- T1: Automated CI (parity check, unit tests, linting)
- T2: Instrumented benchmarks (frame time, latency, SPI throughput)
- T3: Developer review (5 scenarios)
- T4: Child evaluation protocol (ages 4-6)

### [face-visual-language.md](face-visual-language.md)
Design reference for visual appearance. Defines intended look of all 13 moods, 13 gestures, and 8 conversation states. All parameter values marked [Provisional]. Includes:
- §1: Coordinate space, TN panel luma floor rule (L ≥ 85)
- §2-4: Per-mood eye scale, color, expression targets
- §5: Silhouette distinctiveness matrix, parity notes

## Personality Engine

### [personality-engine-spec-stage1.md](personality-engine-spec-stage1.md)
Research & decisions. 7 research buckets (safety psychology, temperament, memory, relationships, initiative, LLM selection, prompt engineering, device/server split). 10 decision points (PE-1 through PE-10) with approved options.

### [personality-engine-spec-stage2.md](personality-engine-spec-stage2.md)
**Full implementation-ready spec** (~1340 lines). The primary reference for personality engine work.
- §1-3: 5 personality axes, continuous affect vector (valence, arousal), decaying integrator
- §4: 13 mood anchors in VA space, asymmetric hysteresis projection
- §5: 20 axis-derived parameters
- §6: Impulse catalog (stimulus → affect delta)
- §7: Guardrails (duration caps, intensity caps, context gate)
- §8: Layer 0 (deterministic) vs Layer 1 (LLM-enhanced) architecture
- §9: Memory system (5 decay tiers, COPPA compliant)
- §10: Worker protocol (personality snapshot struct)
- §11: Tick loop integration (suppress-then-read model)
- §13: Evaluation metrics

### [pe-face-comm-alignment.md](pe-face-comm-alignment.md)
Alignment report reconciling the two independently-researched specs. 5 conflicts resolved:
1. Guardrail enforcement point (tiered model)
2. SURPRISED reclassification
3. Mood transition ownership
4. CONFUSED mood addition (13th mood)
5. Suppress-then-read model (replaces queue model)

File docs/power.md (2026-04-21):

# Power

## Goal

Run the Pi 5 + 2× ESP32-S3 + TFT face + 2× Yahboom TT gearmotors from a single
18650 pack with UPS function (seamless AC ↔ battery switchover) and software-
readable battery telemetry.

## Topology (single-rail, 5 V)

```
  USB-C (AC) ─┐
              ├─► Waveshare UPS HAT (B) ─► 5 V / 5 A ─┬─► Pi 5
  2× 18650 ───┘                                       │     └─► USB 5 V ─► ESP32-face + ESP32-reflex
                (2S, 7.4 V nominal)                   │
                                                      └─► TB6612 VM ─► TT motors
```

Everything downstream of the HAT lives on a shared 5 V rail. The HAT owns
charging, undervoltage cutoff, UPS switchover, and reports pack voltage +
current over I²C (INA219-class). Pi PMIC monitors its own 5 V rail
independently as a second opinion via `vcgencmd get_throttled` and sysfs
hwmon (the supervisor's `PiPMICMonitor`).

### Why a single rail is OK here

The "dirty rail / clean rail" split in the old version of this doc was sized
for unknown motors. The actual motors — Yahboom TT gearmotors, 1440
counts/rev, TT-family spec — draw ~150 mA per motor continuous and
~500–700 mA stall. Two motors = ~300 mA continuous, ~1.5 A peak during a
direction flip. That's inside the 5 A HAT budget with the Pi pulling
2–2.5 A on top.

TB6612 VM is spec'd 4.5–13.5 V. A 1000 µF bulk cap on VM input absorbs
motor-surge sag so the rail stays above the 4.5 V floor during direction
flips. No dedicated motor supply needed at this scale.

## Battery

- **2× 18650 in series** in the Waveshare UPS HAT (B) Pi 5 pogo-pin variant.
- Cells: start with whatever's on hand. For real runtime (≥1 hr) replace with
  Samsung 30Q / LG HG2 / Molicel P26A from a reputable US source.
- Charger: the UPS HAT charges via its USB-C input; no external 18650
  charger needed during normal use. A dedicated 18650 charger (the one
  already on hand) stays useful for capacity tests + cell rotation.

## Telemetry chain

- HAT INA219 → `/dev/i2c-1` → supervisor `WaveshareUpsBMonitor` (Phase 2).
- Pi 5 PMIC → `/sys/class/hwmon/*` + `vcgencmd get_throttled` → supervisor
  `PiPMICMonitor` (Phase 1, shipping now).
- Both flow into `RobotState.power` (`PowerState` dataclass) and broadcast as
  the nested `power` field on the telemetry WebSocket.
- Dashboard `PowerPanel` renders source + voltage + SoC (when available) +
  PMIC undervoltage pill.
- Planner `WorldState.power` carries the same structure; speech_policy owns
  the low-battery announcement at `soc_pct < power.soc_warn_pct` and
  `soc_pct < power.soc_critical_pct` thresholds, plus any PMIC
  undervoltage event.

## Camera-ribbon interaction (physical)

Pi 5 CSI connectors (CAM0 / CAM1) are on the side edge. Pogo-pin HATs sit
flat over GPIO only and don't block them, but the Pi 5 camera ribbons ship
short — if the HAT's height makes the ribbon tight, swap to a longer
(15 cm+) Pi 5 CSI ribbon.

## Safety notes

- UPS HAT (B) has built-in 2.5 V/cell undervoltage cutoff. Do not bypass.
- Avoid no-name "9900 mAh" 18650s for sustained use — typical real capacity
  is a fraction of the claim and some cells have inadequate protection.
- Always charge through the HAT or a dedicated charger — never plug a bare
  18650 straight to USB.

## Firmware note

`esp32-reflex/main/pin_map.h` historically reserved `GPIO_NUM_1` as
`PIN_VBAT_SENSE` for an on-MCU ADC battery read. That path is obsolete in
this topology (the ESP32 only sees USB 5 V, not pack voltage) and the pin
will be freed in a follow-up cleanup after the HAT is commissioned.

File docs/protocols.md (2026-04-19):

# Protocols

## Transport
USB serial between Raspberry Pi 5 and each ESP32.

USB serial between Raspberry Pi 5 and each ESP32-S3.

All packets use the same wire format:
- Raw: `[type:u8] [seq:u8] [payload:N] [crc16:u16-LE]`
- On wire: COBS-encode the raw bytes, then append `0x00` delimiter
- All multi-byte values are little-endian

## Reflex MCU Protocol (v1)

Command IDs: `0x10–0x1F` | Telemetry IDs: `0x80`

### Commands (supervisor → MCU)

| Command | ID | Payload |
| --- | ---- | --- |
| SET_TWIST | 0x10 | v_mm_s(i16) w_mrad_s(i16) — 4 bytes |
| STOP | 0x11 | reason(u8) — 1 byte |
| ESTOP | 0x12 | (empty) |
| SET_LIMITS | 0x13 | (reserved) |
| CLEAR_FAULTS | 0x14 | mask(u16) — 2 bytes |
| SET_CONFIG | 0x15 | param_id(u8) value(4 bytes) — 5 bytes |

### Telemetry (MCU → supervisor)

| Telemetry | ID | Payload |
| --- | ---- | --- |
| STATE | 0x80 | speed_l(i16) speed_r(i16) gyro_z(i16) battery_mv(u16) fault_flags(u16) range_mm(u16) range_status(u8) — 13 bytes |

### Fault Flags (bitfield)

| Bit | Name |
| --- | --- |
| 0 | CMD_TIMEOUT |
| 1 | ESTOP |
| 2 | TILT |
| 3 | STALL |
| 4 | IMU_FAIL |
| 5 | BROWNOUT |
| 6 | OBSTACLE |

## Face MCU Protocol (v3)

Command IDs: `0x20–0x2F` | Telemetry IDs: `0x90–0x9F`

Applies to current face display backend (`esp32-face`).

### Commands (supervisor → MCU)

| Command | ID | Payload |
| --- | ---- | --- |
| SET_STATE | 0x20 | mood_id(u8) intensity(u8) gaze_x(i8) gaze_y(i8) brightness(u8) — 5 bytes  |
| GESTURE | 0x21 | gesture_id(u8) duration_ms(u16) — 3 bytes |
| SET_SYSTEM | 0x22 | mode(u8) phase(u8) param(u8) — 3 bytes |
| SET_TALKING | 0x23 | talking(u8) energy(u8) — 2 bytes |
| SET_FLAGS | 0x24 | flags(u8) — 1 byte |
| SET_CONV_STATE| 0x25 | conv_state(u8) — 1 byte |

SET_TALKING controls the "speaking" animation state. The supervisor sends
`talking=1` during local speaker playback with periodic energy updates and sends
`talking=0` when playback ends.

SET_FLAGS controls renderer/animation feature toggles. The `flags` byte is a
bitfield; unset bits disable the corresponding feature:

| Bit | Constant | Description |
| --- | --- | --- |
| 0 | IDLE_WANDER | Idle gaze wander animation |
| 1 | AUTOBLINK | Autonomous blink timing |
| 2 | SOLID_EYE | Solid fill eyes (no gradient) |
| 3 | SHOW_MOUTH | Render mouth feature |
| 4 | EDGE_GLOW | Edge glow effect |
| 5 | SPARKLE | Sparkle particle effect |
| 6 | AFTERGLOW | Afterglow trail effect |

SET_CONV_STATE sets the current conversation phase, which drives the border
animation rendered around the face display:

| Value | Name | Border Effect |
| ----- | --- | --- |
| 0 | IDLE | No border |
| 1 | ATTENTION | Pulse on |
| 2 | LISTENING | Steady colored frame |
| 3 | PTT | PTT-color frame |
| 4 | THINKING  | Animated shimmer |
| 5 | SPEAKING  | Ripple/pulse driven by speech energy |
| 6 | ERROR | Red flash |
| 7 | DONE | Fade out |

Command channel semantics in `esp32-face`:
- `SET_STATE`, `SET_SYSTEM`, `SET_TALKING`, `SET_FLAGS`, `SET_CONV_STATE` are latched last-value channels.
- `GESTURE` is a FIFO one-shot queue.
- High-rate `SET_TALKING` updates must not overwrite queued gestures or latched mood/system.

### Telemetry (MCU → supervisor)

| Telemetry | ID | Payload |
| --- | ---- | --- |
| FACE_STATUS  | 0x90 | v1: mood_id(u8) active_gesture(u8) system_mode(u8) flags(u8) — 4 bytes; v2: adds cmd_seq_last_applied(u32) + t_state_applied_us(u32) — 12 bytes total |
| TOUCH_EVENT  | 0x91 | event_type(u8) x(u16) y(u16) — 5 bytes |
| BUTTON_EVENT | 0x92 | button_id(u8) event_type(u8) state(u8) reserved(u8) — 4 bytes |
| HEARTBEAT | 0x93 | base payload: uptime + tx counters + USB diagnostics + ptt_listening (68 bytes) + optional perf tail (56 bytes, parsed by length) |

`BUTTON_EVENT` IDs:
- button `0`: PTT (tap-toggle)
- button `1`: ACTION (click)

UI note: face-v2 renders these as small bottom-corner icon controls; telemetry IDs and event types are unchanged.

`BUTTON_EVENT` types:
- `0`: PRESS
- `1`: RELEASE
- `2`: TOGGLE
- `3`: CLICK

`HEARTBEAT` optional perf tail fields (appended only when present):
- `window_frames(u32)`
- `frame_us_avg(u32)`, `frame_us_max(u32)`
- `render_us_avg(u32)`, `render_us_max(u32)`
- `eyes_us_avg(u32)`, `mouth_us_avg(u32)`, `border_us_avg(u32)`, `effects_us_avg(u32)`, `overlay_us_avg(u32)`
- `dirty_px_avg(u32)`, `spi_bytes_per_s(u32)`, `cmd_rx_to_apply_us_avg(u32)`
- `perf_sample_div(u16)`, `dirty_rect_enabled(u8)`, `afterglow_downsample(u8)`

### Mood IDs (canonical — C++ `face_state.h` is source of truth)

| ID  | Name | Description |
| --- | --- | --- |
| 0 | NEUTRAL | Calm, attentive default |
| 1 | HAPPY | Pleased, upturned eyes |
| 2 | EXCITED | Wide open, high energy |
| 3 | CURIOUS | One brow raised, attentive |
| 4 | SAD | Droopy, glistening |
| 5 | SCARED | Wide eyes, shrunk pupils |
| 6 | ANGRY | Narrowed, intense (mild for kids) |
| 7 | SURPRISED | Wide open, raised brows |
| 8 | SLEEPY | Half-closed, slow blinks |
| 9 | LOVE | Heart-shaped / warm glow |
| 10  | SILLY | Cross-eyed or asymmetric |
| 11  | THINKING  | Looking up/aside |
| 12  | CONFUSED  | Head-tilt, questioning look |

### Gesture IDs

| ID  | Name | Trigger |
| --- | --- | --- |
| 0 | BLINK | Auto / commanded |
| 1 | WINK_L | Playful emphasis |
| 2 | WINK_R | Playful emphasis |
| 3 | CONFUSED  | Doesn't understand |
| 4 | LAUGH | Joke / funny moment |
| 5 | SURPRISE  | Sudden realization |
| 6 | HEART | Affection burst |
| 7 | X_EYES | Silly "broken" |
| 8 | SLEEPY | Drifting off |
| 9 | RAGE | Frustrated (comedic) |
| 10  | NOD | Agreement/acknowledgment |
| 11  | HEADSHAKE | Disagreement/no |
| 12  | WIGGLE | Playful shimmy |

Canonical gesture names used by server/supervisor validation:
`blink, wink_l, wink_r, confused, laugh, surprise, heart, x_eyes, sleepy, rage, nod, headshake, wiggle`

### System Modes

| ID  | Name |
| --- | --- |
| 0 | NONE |
| 1 | BOOTING |
| 2 | ERROR_DISPLAY |
| 3 | LOW_BATTERY |
| 4 | UPDATING |
| 5 | SHUTTING_DOWN |

### Touch Event Types

| ID  | Name |
| --- | --- |
| 0 | PRESS |
| 1 | RELEASE |
| 2 | DRAG |

### FACE_STATUS Flags (bitfield)

| Bit | Name |
| --- | --- |
| 0 | touch_active  |
| 1 | talking |
| 2 | ptt_listening |

## Audio

Audio is owned by supervisor-side USB devices in face-v2.

- Face MCU no longer carries speaker/mic PCM over CDC protocol.
- Face MCU only receives `SET_TALKING` energy updates to animate speech.
- Touch/button telemetry from face is used by supervisor to drive local audio control
  (PTT toggle and action events).

## Conversation Pipeline

For real-time conversation (kid speaks → robot responds with emotional speech):

```
Kid speaks → Pi USB mic → Pi supervisor → 3090 Ti server
  → Whisper STT → Qwen3 14B LLM → Orpheus TTS
  → emotion + audio stream back to Pi → Pi USB speaker + ESP32 face animation
```

The server exposes `WS /converse` for bidirectional streaming. Emotion metadata
is sent before audio so the face changes expression before the robot starts speaking.

See the full pipeline design in the plan document.

## MCU Benchmark Harness

Cross-MCU performance benchmark with a shared core and target-specific adapters.
Collects time-series telemetry samples, computes percentile stats, writes versioned
JSON artifacts, and supports A/B comparison.

### Quick Start

```bash
# Face benchmark against live supervisor (5 scenarios, 100 samples each)
just mcu-benchmark --target face --base-url http://192.168.55.201:8080

# Custom sample count + output directory
just mcu-benchmark --target face --samples 200 --out docs/perf

# Reflex benchmark (idle only — safe default)
just mcu-benchmark --target reflex --base-url http://192.168.55.201:8080

# Reflex with motion scenario (requires explicit opt-in)
just mcu-benchmark --target reflex --allow-motion --base-url http://...

# Compare two artifacts (A/B telemetry overhead, <=1% FPS drop gate)
just mcu-benchmark --compare docs/perf/baseline.json docs/perf/test.json
```

### Supervisor API

| Endpoint | Method | Description |
|---|---|---|
| `/debug/mcu_benchmark` | GET | Current run status (idle/running/completed/failed) |
| `/ws` | WS `mcu_benchmark.start` | Start a benchmark run |
| `/ws` | WS `mcu_benchmark.cancel` | Cancel a running benchmark |

WS start payload:
```json
{
  "type": "mcu_benchmark.start",
  "target": "face",
  "profile": "stage4_face",
  "samples": 100,
  "base_url": "http://localhost:8080",
  "out_dir": "docs/perf",
  "allow_motion": false
}
```

### Face Scenarios

| Scenario | Setup | What it stresses |
|---|---|---|
| `idle` | Neutral mood, no animation | Baseline frame cost |
| `listening_proxy` | LISTENING conv state | Border pulse animation |
| `thinking_border` | THINKING conv state | Heavy border animation (hotspot) |
| `talking_energy` | Happy + talking + energy=180 | Mouth animation + energy |
| `rage_effects` | Angry mood | Effects pipeline |

### Reflex Scenarios

| Scenario | Requires | What it measures |
|---|---|---|
| `idle_hold` | (always) | State update rate, jitter, age |
| `step_response` | `--allow-motion` | Velocity tracking error |

### Output Artifacts

Written to `docs/perf/` as versioned JSON (schema v2):

```json
{
  "version": 2,
  "target": "face",
  "profile": "stage4_face",
  "captured_at": "2026-02-26T...",
  "endpoint": "http://...",
  "scenarios": {
    "idle": {
      "frames": 6400,
      "frame_us_avg": 75000,
      "frame_us_max": 80000,
      "frame_us_p50": 74500.0,
      "frame_us_p95": 79200.0,
      "render_us_avg": 7500,
      "render_us_p50": 7200.0,
      "render_us_p95": 8100.0,
      "border_us_avg": 23000,
      "border_us_p50": 22800.0,
      "border_us_p95": 24100.0,
      "mouth_us_avg": 6900,
      "mouth_us_p50": 6800.0,
      "mouth_us_p95": 7200.0,
      "fps_est": 13.33,
      "eyes_us_avg": 12700,
      "effects_us_avg": 17000,
      "overlay_us_avg": 5,
      "dirty_px_avg": 9600,
      "spi_bytes_per_s": 192000,
      "cmd_rx_to_apply_us_avg": 1000,
      "samples": 100,
      "elapsed_s": 99.1
    }
  }
}
```

Legacy fields (`frame_us_avg`, `frame_us_max`, etc.) are preserved for backward
comparison with v1 artifacts. New fields: `frame_us_p50`, `frame_us_p95`,
`render_us_p50/p95`, `border_us_p50/p95`, `mouth_us_p50/p95`.

### Compare Mode

Compares two artifacts and reports per-scenario FPS delta with pass/fail:

```bash
just mcu-benchmark --compare docs/perf/baseline.json docs/perf/with_telemetry.json
```

Output includes `fps_drop_pct` per scenario and `overall_pass` (true if all
scenarios stay within the threshold, default <=1% FPS drop).

### Architecture

```
supervisor/api/
├── mcu_benchmark.py          # Shared core: stats, lifecycle, artifact I/O, compare, CLI
├── mcu_benchmark_face.py     # Face adapter: 5 scenarios, heartbeat polling, p50/p95
└── mcu_benchmark_reflex.py   # Reflex adapter: rate/jitter/age, opt-in motion
```

The harness runs against an already-running supervisor endpoint. It polls
`/debug/devices` for telemetry and sends face/reflex commands via `/ws`.
Flashing/deploy remains manual.

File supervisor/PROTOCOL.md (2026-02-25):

# Robot Buddy v2 — Unified Message Protocol Specification

**Version:** 2.0-draft
**Date:** 2026-02-20
**Status:** Canonical reference for all message boundaries

---

## 1. Design Principles

### 1.1 Monotonic Clocks Only

No wall clock (`time.time()`, `gettimeofday`, NTP) in any control path, safety decision, or causality chain. Wall time may appear only in human-readable log decorations. All timing uses:

- **Pi:** `time.monotonic_ns()` (`CLOCK_MONOTONIC`, nanosecond resolution)
- **Reflex MCU:** `esp_timer_get_time()` (microseconds since boot)
- **Face MCU:** `esp_timer_get_time()` (microseconds since boot)
- **Server:** `time.monotonic_ns()` (informational only — never used for control decisions)

### 1.2 Timestamp at Acquisition Time

Every datum is timestamped when it was *acquired*, not when it was published, queued, serialized, or received:

- IMU samples → at I2C/SPI read completion or DRDY interrupt
- Encoder readings → at control loop tick boundary
- Ultrasonic range → at echo completion
- Camera frames → sensor timestamp if available, else Pi receive time
- Vision detections → reference the source frame timestamp, not detection-completion time
- Button/touch events → at interrupt/detection on the MCU
- Motor PWM applied → when update committed

### 1.3 Sequence Numbers Everywhere

Every message carries a monotonically increasing sequence number scoped to its source. Gaps indicate drops. Duplicates indicate retransmission or bugs.

- MCU binary protocol: `u32` (upgraded from `u8` in v1)
- NDJSON messages: `int` (unbounded, practically `u64`)
- Server plan responses: echo request `seq` plus unique `plan_id`

### 1.4 Stable Message Contract

All schemas are defined as if they were a Rust `enum` with typed payloads. This means:

- Every message has exactly one canonical schema — no polymorphic "bag of keys"
- New message types are additive (never redefine existing type IDs)
- All fields have explicit types and units in their names (`_mm`, `_ms`, `_mrad_s`, `_ns`, `_us`)
- NDJSON messages are plain JSON — no Python-specific serialization

### 1.5 No Raw Uncompressed Frames Across Process Boundaries

Workers never send raw uncompressed image frames or PCM buffers to Core as opaque blobs. All inter-process messages on the Core↔Worker NDJSON channel are structured. Compressed frames (JPEG) may cross boundaries when explicitly enabled, wrapped in typed NDJSON with metadata (e.g., `vision.frame.jpeg` with `frame_seq`).

Rule: only semantic events and explicitly-requested compressed frames cross the Core↔Worker NDJSON boundary. Raw audio streams use a dedicated data plane (see §6.6).

### 1.6 Schema Version

All NDJSON envelopes carry a `v` field (integer). Binary MCU packets carry an implicit version negotiated via handshake. Unknown fields are ignored by receivers; incompatible versions are rejected.

### 1.7 Core Is the Control Plane, Not the Data Plane

Core is the control plane, not the data plane. Raw audio streams between workers directly via dedicated sockets. Core sends control signals (start/stop/cancel conversation, start/stop mic) and receives semantic events (energy, transcript, emotion, gesture, state changes), but never forwards raw audio bytes.

### 1.8 Wire Format Is Canonical

The NDJSON wire format (§3.1) is the canonical schema. Payload fields are inline — not nested inside a `payload` object. Internal Python dataclasses may use any convenient representation, but serialization to/from the wire must produce the flat inline form:

```json
{"v": 2, "type": "tts.event.energy", "src": "tts", "seq": 11, "t_ns": 0, "energy": 180}
```

Not:

```json
{"v": 2, "type": "tts.event.energy", "src": "tts", "seq": 11, "t_ns": 0, "payload": {"energy": 180}}
```

---

## 2. Clock Domains and Synchronization

### 2.1 Clock Domains

| Domain | Source | Resolution | Type | Epoch |
|---|---|---|---|---|
| Pi | `CLOCK_MONOTONIC` | nanoseconds | `i64` | Pi boot |
| Reflex MCU | `esp_timer_get_time()` | microseconds | `u64` | MCU boot |
| Face MCU | `esp_timer_get_time()` | microseconds | `u64` | MCU boot |
| Server | `time.monotonic_ns()` | nanoseconds | `i64` | Server boot |

Field naming convention encodes domain and unit:
- `t_pi_ns` — Pi monotonic nanoseconds
- `t_src_us` — MCU source monotonic microseconds
- `t_pi_rx_ns` — Pi receive timestamp
- `t_server_ns` — Server monotonic (informational only)

### 2.2 TIME_SYNC Protocol (Pi ↔ MCU)

Lightweight ping/pong to estimate clock offset between Pi and each MCU.

**New packet types:**

| Type ID | Direction | Name |
|---|---|---|
| `0x06` | Pi → MCU | `TIME_SYNC_REQ` |
| `0x86` | MCU → Pi | `TIME_SYNC_RESP` |

**TIME_SYNC_REQ payload (8 bytes):**
```c
struct TimeSyncReqPayload {
    uint32_t ping_seq;    // incrementing counter
    uint32_t reserved;
};
```

**TIME_SYNC_RESP payload (12 bytes):**
```c
struct TimeSyncRespPayload {
    uint32_t ping_seq;    // echo
    uint64_t t_src_us;    // MCU time at response
};
```

**Scheduling:** TIME_SYNC runs on its own async task, independent of the 50 Hz tick loop. It must never block the tick loop or be gated by tick timing. The sync task updates a shared `ClockSync` object atomically; the tick loop reads it read-only.

```python
@dataclass(slots=True)
class ClockSync:
    state: str              # "unsynced" | "synced" | "degraded"
    offset_ns: int          # best estimate (from min-RTT sample)
    rtt_min_us: int         # minimum RTT observed in window
    drift_us_per_s: float   # estimated drift rate
    samples: int            # total samples collected
    t_last_sync_ns: int     # Pi monotonic of last accepted sample
```

**One outstanding ping at a time:** The sync task sends one `TIME_SYNC_REQ` and waits for the corresponding `TIME_SYNC_RESP` (matched by `ping_seq`) before sending the next. If no response arrives within 500 ms, the ping is considered lost and the next one may be sent. This prevents RTT measurement corruption from pipelined pings.

**Pi-side algorithm:**

1. Record `t_pi_tx_ns = time.monotonic_ns()` before sending
2. On response, record `t_pi_rx_ns = time.monotonic_ns()`
3. `rtt_ns = t_pi_rx_ns - t_pi_tx_ns`
4. `offset_ns = t_pi_rx_ns - (t_src_us * 1000) - (rtt_ns / 2)`
5. Sliding window of 16 samples; use the **minimum RTT** sample as the offset estimate
6. Initial: 5 Hz for first 20 samples. Steady-state: 2 Hz.

**v1 devices:** TIME_SYNC is only active for devices that completed v2 protocol negotiation (§3.2). For v1 devices, clock sync is disabled — `ClockSync.state` remains `"unsynced"` permanently, and all features that depend on clock offset (causality tracing, drift estimation) report "unavailable" rather than using stale or zero values.

**Offset application:**
```
t_pi_est_ns = t_src_us * 1000 + offset_ns
```
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

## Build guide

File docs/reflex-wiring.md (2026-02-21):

# Reflex MCU Wiring Diagram

## ESP32-S3 WROOM Breakout — Finalized Pin Map

> **Source of truth**: `esp32-reflex/main/pin_map.h`
> This document mirrors the firmware. If they disagree, the firmware wins.

### Reserved Pins (DO NOT USE)

| GPIO | Function | Rule |
|---|---|---|
| 0 | Boot strap | No runtime logic |
| 19, 20 | USB D+/D- | Leave alone |
| 35, 36, 37 | PSRAM (octal) | Leave alone |
| 43, 44 | UART0 TX/RX | Leave alone (console) |
| 45 | VSPI | Fine but unused |
| 48 | WS2812 onboard LED | Avoid unless intentional |

---

### Wiring Diagram

```
                    ESP32-S3 WROOM BREAKOUT
                    ┌────────────────────┐
                    │                    │
              3V3 ──┤ 3V3          GND  ├── GND (common)
                    │                    │
   [VBAT ÷] ─────── ┤ GPIO1   ADC1_CH0  ├                    ← Battery sense (future)
   [Echo ÷] ─────── ┤ GPIO2   ADC1_CH1  ├                    ← Ultrasonic echo (5V÷3.3V)
                    │                    │
   TB6612 PWMA ──── ┤ GPIO4    LEDC_CH0 ├ ←── 100k pulldown  ← Left motor PWM
   TB6612 PWMB ──── ┤ GPIO5    LEDC_CH1 ├ ←── 100k pulldown  ← Right motor PWM
   TB6612 AIN1 ──── ┤ GPIO6             ├                    ← Left fwd direction
   TB6612 AIN2 ──── ┤ GPIO7             ├                    ← Left rev direction
   TB6612 STBY ──── ┤ GPIO8             ├ ←── 100k pulldown  ← Motor enable (active HIGH)
                    │                    │
   Enc Left A ───── ┤ GPIO9             ├                    ← Left encoder ch A
   Enc Left B ───── ┤ GPIO10            ├                    ← Left encoder ch B
   Enc Right A ──── ┤ GPIO11            ├                    ← Right encoder ch A
   Enc Right B ──── ┤ GPIO12            ├                    ← Right encoder ch B
                    │                    │
   E-Stop SW ────── ┤ GPIO13            ├ ←── 10k pullup 3V3 ← Active-low, NC to GND
                    │                    │
   TB6612 BIN1 ──── ┤ GPIO15            ├                    ← Right fwd direction
   TB6612 BIN2 ──── ┤ GPIO16            ├                    ← Right rev direction
                    │                    │
   BMI270 SDA ───── ┤ GPIO17  I2C1_SDA  ├                    ← Qwiic (2.2k on breakout)
   BMI270 SCL ───── ┤ GPIO18  I2C1_SCL  ├                    ← Qwiic (2.2k on breakout)
                    │                    │
   Range TRIG ───── ┤ GPIO21            ├                    ← Ultrasonic trigger (10µs)
                    │                    │
                    │       USB-C        │
                    │    (GPIO19/20)     │
                    └────────┬───────────┘
                             │
                         To Pi / PC
```

---

### Motor Driver — TB6612FNG

```
                         TB6612FNG
                    ┌──────────────────┐
   ESP32 GPIO4 ───→│ PWMA        AOUT1├───→ Left Motor +
   ESP32 GPIO6 ───→│ AIN1        AOUT2├───→ Left Motor -
   ESP32 GPIO7 ───→│ AIN2             │
                    │                  │
   ESP32 GPIO5 ───→│ PWMB        BOUT1├───→ Right Motor +
   ESP32 GPIO15 ──→│ BIN1        BOUT2├───→ Right Motor -
   ESP32 GPIO16 ──→│ BIN2             │
                    │                  │
   ESP32 GPIO8 ───→│ STBY         VCC ├───→ 3.3V (logic)
        GND ──────→│ GND          VM  ├───→ VBAT (motor power, 2S LiPo)
                    └──────────────────┘

   Direction truth table:
     IN1=1, IN2=0 → Forward
     IN1=0, IN2=1 → Reverse
     IN1=1, IN2=1 → Short brake
     IN1=0, IN2=0 → Coast

   Boot safety: 100k pulldown on PWMA (GPIO4), PWMB (GPIO5), STBY (GPIO8)
   ensures motors are OFF until firmware explicitly enables them.
```

---

### IMU — SparkFun Qwiic BMI270

```
   SparkFun Qwiic BMI270 Breakout
   ┌────────────────────────────┐
   │  Qwiic connector (JST-SH) │
   │  ┌──────┐                  │
   │  │ BLK  │ GND ─────────── │───→ GND
   │  │ RED  │ 3V3 ─────────── │───→ 3.3V
   │  │ BLU  │ SDA ─────────── │───→ ESP32 GPIO17
   │  │ YEL  │ SCL ─────────── │───→ ESP32 GPIO18
   │  └──────┘                  │
   │                            │
   │  ADR jumper: default = 0x68 (SDO→GND)               │
   │  Cut center + bridge to VDDIO pad for 0x69           │
   │                            │
   │  Onboard: 2.2k pullups on SDA/SCL (no external needed)│
   └────────────────────────────┘

   I2C bus: I2C_NUM_1, 400 kHz fast mode
   Firmware address: 0x68 (verify with I2C scan in Phase 1)
```

---

### Ultrasonic Range Sensor — HC-SR04

```
                    HC-SR04
                ┌──────────────┐
    5V ────────→│ VCC          │
    GND ───────→│ GND          │
                │              │
   ESP32 GPIO21 ←──│ TRIG     │   (direct 3.3V → 5V tolerant input)
                │              │
                │ ECHO ────────│───┐
                └──────────────┘   │
                                   │     5V → 3.3V voltage divider
                             10k   ├──── ┤
                                   │     │
                      ESP32 GPIO2 ←┤     │     Optional: 100-330 ohm
                                   │     │     series resistor before GPIO2
                             20k   ├──── ┤     for ESD protection
                                   │
                                  GND

   Divider output: 5V × 20k/(10k+20k) = 3.33V (safe for ESP32)
```

---

### E-Stop & Battery Sense

```
   E-Stop (GPIO13):                    Battery Sense (GPIO1):
   ┌─────────────────────┐             ┌─────────────────────┐
   │                     │             │                     │
   │  3V3 ──── 10k ─┬── │             │  VBAT ── 100k ─┬── │
   │                 │   │             │                 │   │
   │  ESP32 GPIO13 ──┘   │             │  ESP32 GPIO1 ──┘   │
   │                 │   │             │                 │   │
   │  E-Stop SW ─── GND  │             │            47k ┤   │
   │  (NC = HIGH = OK)   │             │                 │   │
   │  (pressed = LOW      │             │   0.1µF cap ── GND  │
   │   = ESTOP active)   │             │                     │
   │                     │             │  Divider: VBAT × 47k/(100k+47k) │
   │  Optional: 0.1µF    │             │  @ 8.4V (2S full): 2.68V (safe) │
   │  cap GPIO13→GND     │             │  @ 6.0V (2S low):  1.92V        │
   │  for debounce       │             │                     │
   └─────────────────────┘             └─────────────────────┘
```

---

### Passive Component BOM

| Component | Location | Purpose |
|---|---|---|
| 3x 100k resistor | GPIO4→GND, GPIO5→GND, GPIO8→GND | Motor boot safety pulldowns |
| 1x 10k resistor | 3V3→GPIO13 | E-stop pullup |
| 1x 10k resistor | HC-SR04 ECHO → divider node | Echo voltage divider (top) |
| 1x 20k resistor | Divider node → GND | Echo voltage divider (bottom) |
| 1x 100-330 ohm | Divider node → GPIO2 (optional) | ESD series protection |
| 1x 100k resistor | VBAT → divider node | Battery sense (top, future) |
| 1x 47k resistor | Divider node → GND | Battery sense (bottom, future) |
| 1x 0.1uF cap | GPIO13 → GND (optional) | E-stop debounce |
| 1x 0.1uF cap | Battery ADC node → GND | ADC noise filter |

---

### Power Distribution

```
   2S LiPo (6.0–8.4V)
          │
          ├──→ TB6612FNG VM (motor power, direct)
          │
          ├──→ Voltage divider → GPIO1 (battery sense)
          │
          ├──→ 5V Buck Regulator
          │         │
          │         ├──→ HC-SR04 VCC (5V)
          │         │
          │         └──→ 3.3V LDO (or ESP32 breakout onboard regulator)
          │                  │
          │                  ├──→ ESP32-S3 3.3V
          │                  ├──→ TB6612FNG VCC (logic, 3.3V)
          │                  ├──→ SparkFun BMI270 3V3
          │                  └──→ E-stop pullup
          │
          └──→ GND (common ground for everything)
```

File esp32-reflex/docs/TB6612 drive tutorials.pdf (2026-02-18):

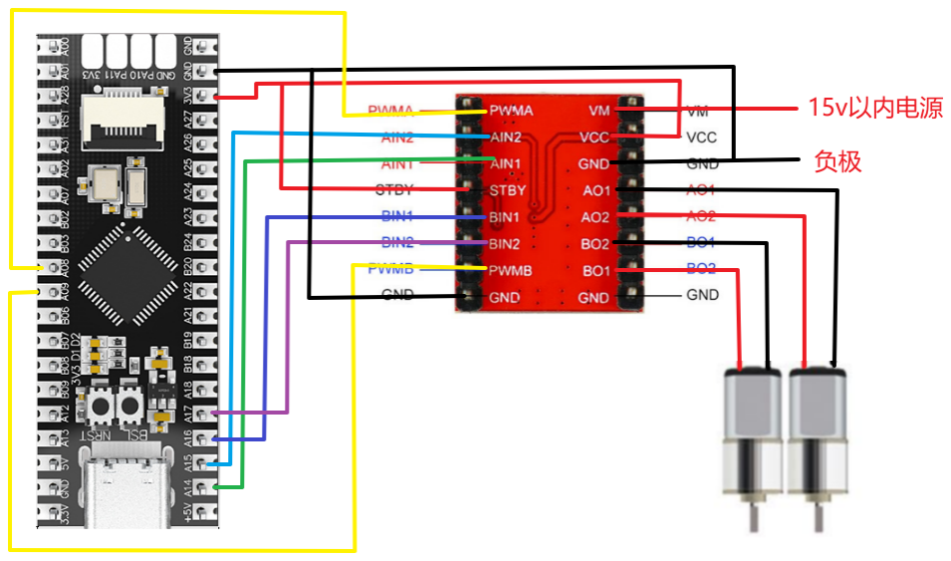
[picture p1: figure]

MSPM0G3507 | TB6612
PA8 | PWMA
PA14 | AIN1
PA15 | AIN2
MSPM0G3507 | TB6612
PA9 | PWMB
PA16 | BIN1
PA17 | BIN2

# TB6612 drive tutorials

## 1. Learning objectives

Use TB6612 motor driver module to drive dual-channel motors.

## 2. Hardware connection

MSPM0G3507 and TB6612 pin connection

A motor：

B motor：

TB6612 motor driver module pin description.

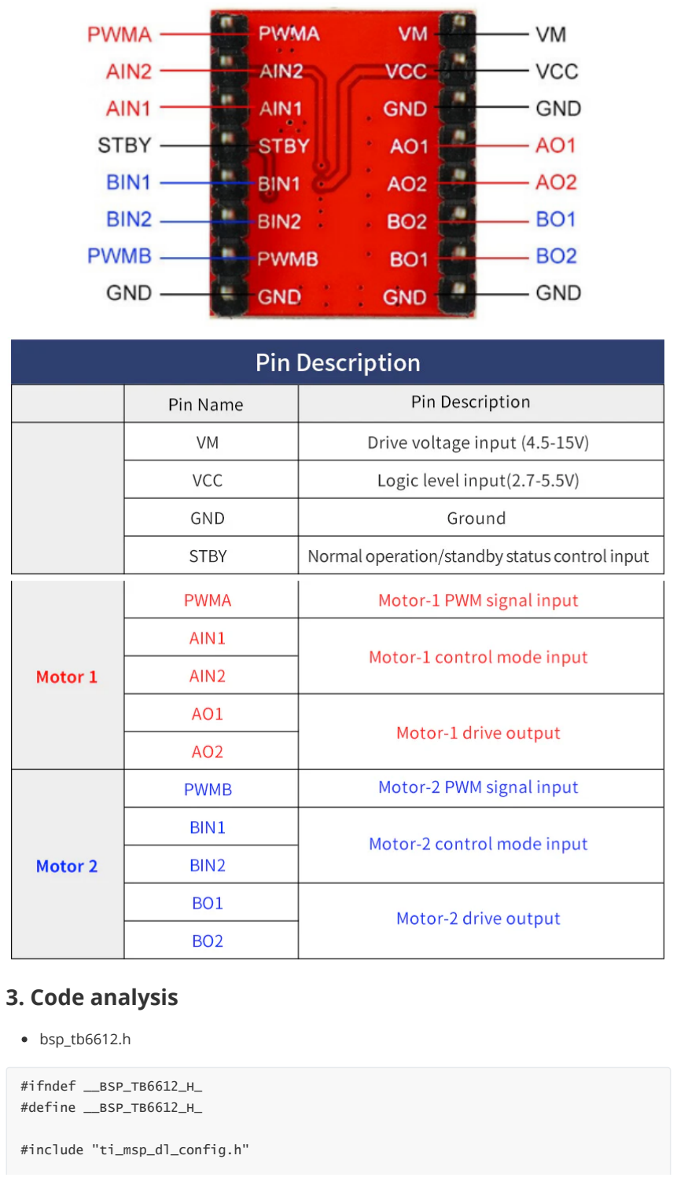
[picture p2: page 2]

## 3. Code analysis

bsp_tb6612.h

#ifndef __BSP_TB6612_H_

#define __BSP_TB6612_H_

#include "ti_msp_dl_config.h"

The macro definition part defines how to control the direction of the motor. TB6612 controls the direction of the motor through two pins. When one pin is high and the other is low, the motor rotates in one direction; otherwise, it rotates in the opposite direction.

AIN1_OUT and AIN2_OUT control the direction of motor A.

BIN1_OUT and BIN2_OUT control the direction of motor B.

A_control(uint16_t motor_speed, uint8_t dir): This function is used to control motor A and accepts motor speed (motor_speed) and direction (dir) as parameters.

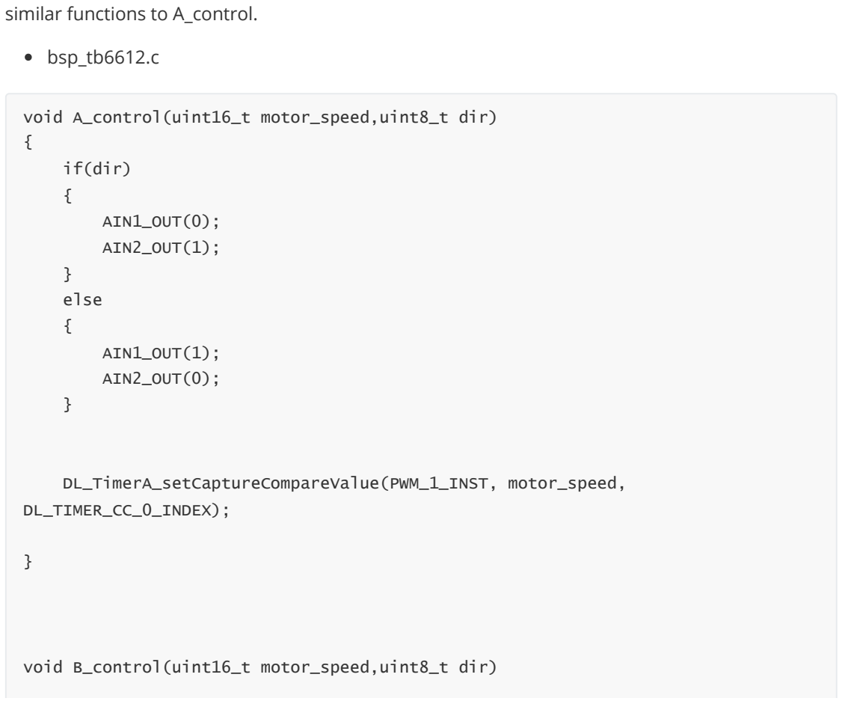
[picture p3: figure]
similar functions to A_control.; bsp_tb6612.c; void A_control(uint16_t motor_speed,uint8_t dir); if(dir); AIN1_OUT(0);; AIN2_OUT(1);; else; AIN1_OUT(1);; AIN2_OUT(0);; DL_TimerA_setCaptureCompareValue(PWM_1_INST, motor_speed,; DL_TIMER_CC_0_INDEX);; void B_control(uint16_t motor_speed,uint8_t dir)

B_control(uint16_t motor_speed, uint8_t dir): This function is used to control motor B and has

//A电机
#define AIN1_OUT(X) ( (X) ? (DL_GPIO_setPins(GPIO_1_PORT,GPIO_1_AIN1_PIN)) : (DL_GPIO_clearPins(GPIO_1_PORT,GPIO_1_AIN1_PIN)) )

#define AIN2_OUT(X) ( (X) ? (DL_GPIO_setPins(GPIO_2_PORT,GPIO_2_AIN2_PIN)) : (DL_GPIO_clearPins(GPIO_2_PORT,GPIO_2_AIN2_PIN)) )

//B电机

#define BIN1_OUT(X) ( (X) ? (DL_GPIO_setPins(GPIO_3_PORT,GPIO_3_BIN1_PIN)) : (DL_GPIO_clearPins(GPIO_3_PORT,GPIO_3_BIN1_PIN)) )

#define BIN2_OUT(X) ( (X) ? (DL_GPIO_setPins(GPIO_4_PORT,GPIO_4_BIN4_PIN)) : (DL_GPIO_clearPins(GPIO_4_PORT,GPIO_4_BIN4_PIN)) )

void A_control(uint16_t motor_speed,uint8_t dir);
void B_control(uint16_t motor_speed,uint8_t dir);

#endif

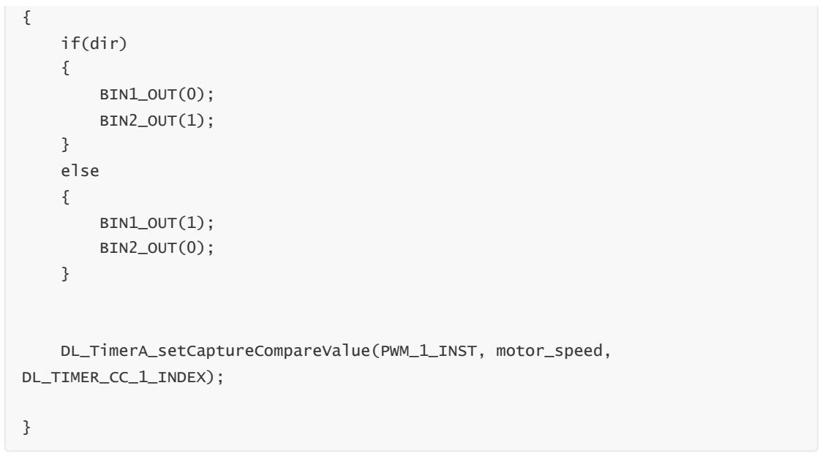
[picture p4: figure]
if(dir); BIN1_OUT(0);; BIN2_OUT(1);; else; BIN1_OUT(1);; BIN2_OUT(0);; DL_TimerA_setCaptureCompareValue(PWM_1_INST, motor_speed,; DL_TIMER_CC_1_INDEX);

Function A_control(uint16_t motor_speed, uint8_t dir) and function B_control(uint16_t motor_speed, uint8_t dir) control motor A and B respectively, determine the rotation direction of the motor according to the dir parameter, and use the motor_speed parameter to set the motor speed.
Note: The project source code must be placed in the SDK path for compilation,
For example, the path: D:\TI\M0_SDK\mspm0_sdk_1_30_00_03\TB6612

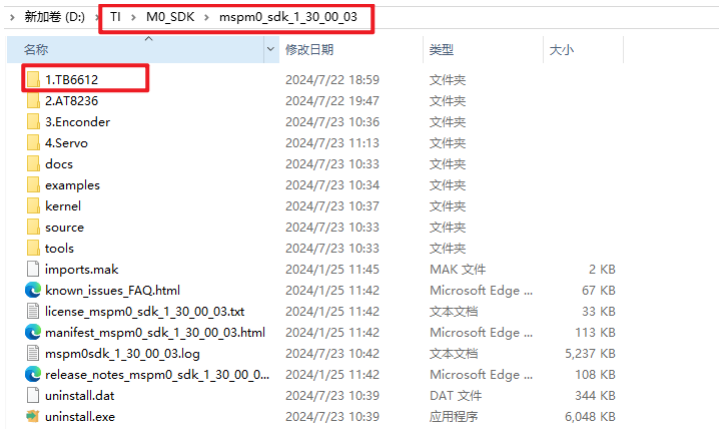
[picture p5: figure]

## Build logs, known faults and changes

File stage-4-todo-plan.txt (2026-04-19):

Stage 4 Cross-MCU Benchmark Harness Plan (Face-First, Reflex-Compatible)
Summary
Build a reusable benchmark harness with a shared core and target adapters, so esp32-face and esp32-reflex use the same execution/reporting model.
Implement face coverage now for Stage 4 needs (including p50/p95 output and telemetry A/B support).
Implement minimal reflex coverage now (rate/jitter/latency proxy + optional motion step), so later reflex tuning reuses the same harness without redesign.
Locked decisions: Hybrid Core and Minimal Reflex Metrics Now.
Public API / Interface Changes
Add WS command mcu_benchmark.start and mcu_benchmark.cancel in http_server.py.
Add benchmark status endpoint GET /debug/mcu_benchmark in http_server.py.
Add a shared benchmark core module in mcu_benchmark.py with a target-adapter interface:
prepare()
setup_scenario(name)
tick(now_s)
ingest_sample(snapshot)
is_complete()
teardown()
Add CLI wrapper in mcu_benchmark.py that starts runs and polls /debug/mcu_benchmark.
Add just recipe for harness execution in justfile.
Implementation Plan
Phase 0: Migrate Existing Face Baseline Logic Into Harness
Port behavior from face_stage4_capture.py into the new face adapter so scenario behavior remains comparable.
Keep scenario names unchanged for continuity: idle, listening_proxy, thinking_border, talking_energy, rage_effects.
Keep legacy averages/max fields in output for backward comparison with existing artifacts in /docs/perf.
Phase 1: Shared Core
Implement run lifecycle, scenario sequencing, retries/timeouts, teardown guarantees, and artifact writing in mcu_benchmark.py.
Implement shared stats helpers:
weighted averages
weighted p50/p95
min/max
elapsed/dropped/error counters
Store run state in memory for /debug/mcu_benchmark (running/completed/failed, scenario progress, latest error, artifact path).
Phase 2: Face Adapter (Stage 4 Requirements)
Data source: face.last_heartbeat.perf from supervisor debug surface.
Metrics per scenario:
existing fields: frame_us_avg, frame_us_max, render_us_avg, stage buckets, dirty_px_avg, spi_bytes_per_s, cmd_rx_to_apply_us_avg
new fields: frame_us_p50, frame_us_p95, render_us_p50, render_us_p95, border_us_p50, border_us_p95, mouth_us_p50, mouth_us_p95
Add compare mode in CLI (--compare A B) to report telemetry overhead and pass/fail against <=1% FPS drop.
Phase 3: Reflex Adapter (Minimal Now, Reusable Later)
Data sources:
/debug/devices for last_state_seq and state age proxy
/status for speed/gyro/fault snapshots
Default scenarios:
idle_hold (no motion, safe default)
step_response only when --allow-motion is set
Metrics:
state_rate_hz_mean
state_period_ms_p50/p95/max
state_age_ms_p50/p95/max
cmd_to_state_ms_p50/p95/max (proxy from command send to next state seq advance)
fault_nonzero_samples and fault_nonzero_pct
motion scenario only: v_error_abs_mm_s_p50/p95/max
Phase 4: Supervisor + CLI Integration
Wire mcu_benchmark.start/cancel in WS command handler in http_server.py.
Add /debug/mcu_benchmark payload shape with run metadata and per-scenario progress.
Add thin CLI in mcu_benchmark.py:
--target face|reflex
--profile stage4_face|reflex_minimal
--base-url
--out
--allow-motion
--compare
Add just mcu-benchmark ... in justfile.
Phase 5: Tests + Docs + TODO
Add unit tests for stats helpers and adapter ingestion in:
test_mcu_benchmark_stats.py
test_mcu_benchmark_face.py
test_mcu_benchmark_reflex.py
Add smoke test for benchmark status endpoint in test_http_server.py.
Update Stage 4 TODO lines in TODO.md:
replace “extend benchmark harness” note with completed harness scope
add explicit reflex-compatible harness line for future tuning reuse
Add usage docs in README.md or docs/protocols.md benchmark section.
Test Cases and Scenarios
Face run writes artifact with legacy + p50/p95 metrics for all five Stage 4 scenarios.
Face compare mode computes telemetry overhead A/B and returns pass/fail against <=1%.
Reflex idle run outputs stable rate/jitter metrics without motion.
Reflex motion run requires --allow-motion; verifies cmd-to-state and tracking error metrics are populated.
Start/cancel/status API behavior:
rejects concurrent run
reports progress while running
marks failed with explicit reason on timeout/disconnect
Backward compatibility:
existing face perf fields still present
no protocol changes required for reflex.
Assumptions and Defaults
Harness runs against an already-running supervisor endpoint; flashing/deploy remains manual.
Face p50/p95 are computed from sampled perf windows exposed by heartbeat telemetry.
Reflex minimal metrics use supervisor-visible telemetry only (no reflex firmware protocol changes in this step).
Motion scenarios are opt-in (--allow-motion) for safety.
Output artifacts remain under docs/perf/ with versioned schema and stable scenario names.

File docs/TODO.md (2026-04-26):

# Robot Buddy — TODO

Single source of implementation truth. All task tracking lives here.

## How to Use This File

- **Priority**: Tasks within each section are listed in recommended execution order (top = highest)
- **Parallel tracks**: Tracks A–D can run concurrently. Dependencies are noted inline.
- **Model tags**: `[opus]` = needs Opus 4.6 (architecture, spec interpretation, complex debugging, prompt engineering). `[sonnet]` = Sonnet handles well (mechanical refactors, test writing, parity checks, README updates).
- **Spec-driven**: Changes that diverge from specs require a spec amendment first. Debate the spec change, update the spec, then implement.

---

## Execution Order & Priority

Living section — reorder as priorities shift. Current recommended sequence:

### Track A: Face Communication (firmware + supervisor)
1. Stage 4.0 parity + hardware polish (system overlays/screens, corner buttons, thinking face read, timing values, docs)
2. Stage 4.1–4.2 firmware optimization (profiling → targeted optimizations)
3. T1–T4 evaluation

### Track B: Personality Engine (server + supervisor)
1–7. _(B1–B5 complete)_
8. _(B6 evaluation: pytest extensions + Studio scenario suite complete)_
9. PE child-safety validation (T4 human protocol — see Face Evaluation)

### Track C: Reflex MCU Commissioning (hardware)
1. Phase 1: IMU bring-up
2. Phase 2: Motors + encoders
3. Phase 3: Ultrasonic range
4. Phase 4: E-stop & safety
5. Phase 5: Closed-loop PID

### Track D: Infrastructure & Tooling
_(all items completed)_

---

## Active Backlog

### Face Communication System

**Stage 4 — Parity + Firmware Display Optimization** `[opus]`
_10 items complete (Stage 4.0 spec/port/parity/buttons/gestures/docs) — see archive_
- [ ] Stage 4.0: Hardware visual pass: Sim V3 vs MCU side-by-side on hardware for all 13 moods (confirm “real” reads match spec intent) `[sonnet]`
- [x] Stage 4.0: Bug: face device buttons not working (PTT/ACTION) — LVGL touch callbacks registered on parent instead of canvas_obj; canvas absorbed all events `[sonnet]`
- [ ] Stage 4.0: Mouth parity: device vs Python sim (Sim V3) vs JS sim (Face Mirror) — migrate firmware mouth to sim upper/lower envelope model; accept when scripted side-by-side shows no obvious mismatch in motion `[sonnet]`
- [ ] Stage 4.0: Gesture parity: HEART_EYES mismatch — port sim heart SDF + scale constants (`HEART_SOLID_SCALE`, `HEART_PUPIL_SCALE`) to firmware; accept when side-by-side scripted checks pass `[sonnet]`
- [ ] Stage 4.0: Blink parity on hardware — eyelids must fully occlude eye fill at full closure (no blue eye outline leak during blink) `[sonnet]`
- [ ] Stage 4.0: Refine THINKING face on hardware (currently reads as angry) `[sonnet]`
- [ ] Stage 4.0: Tune timing values on hardware: ramp durations, hold times, border alpha curves `[sonnet]`
- [ ] Stage 4.0: Face button UX: instant on-device confirmation on press; faster yellow LED blink on PTT error `[sonnet]`
- [ ] Stage 4.1: Baseline integrity gate: revert to float `px_blend(..., float alpha)` as active path; keep fixed-point/u8 helpers disabled/commented with A/B notes; baseline build must pass (`just build-face`)
- [ ] Stage 4.1: Protocol correctness: parse `FACE_STATUS` v1 (4B) and v2 (12B) in supervisor; expose `cmd_seq_last_applied` + `t_state_applied_us` in state/debug
- [ ] Stage 4.1: Low-overhead perf instrumentation in firmware: frame/render/stage timing, dirty px, SPI bytes/s, cmd rx→apply latency (stage sample divisor=8, emit 1 Hz)
- [ ] Stage 4.1: HEARTBEAT optional perf tail (length-based, backward compatible); supervisor + protocol capture decode old/new payload lengths
- [ ] Stage 4.1: Baseline benchmark capture (1000 frames each): idle, listening, thinking, speaking+energy, rage/effects; 2026-02-25 avg/max capture complete, p50/p95 + telemetry overhead A/B (<=1% FPS drop) still pending
- [ ] Stage 4.2: Implement dirty-rectangle invalidation (replace unconditional full-canvas invalidate) and verify normal conversation states stay at p95 frame <= 33.3ms, p50 <= 25ms _(state-aware multi-rect invalidation landed in firmware on 2026-02-25; initial A/B captured but idle/listening were confounded by effects flag state; fixed-flags rerun pending)_
- [x] Stage 4.2: Optimize border/icon hot paths (cache/pre-raster hotspot math) and quantify delta in border-heavy scenarios _(A/B validated on hardware 2026-02-25; see Stage 4.2 snapshot below)_
- [ ] Stage 4.2: Optimize afterglow bandwidth (reduced-resolution buffer + upscale blend behind flag) and quantify effect-on/effect-off cost
- [ ] Stage 4.2: Evaluate SPI/LVGL throughput tuning (40/60/80MHz + queue/buffer settings) after dirty-rect landing; keep best measured config
- [ ] Stage 4.2: Validate perf headroom knobs (`afterglow`, `sparkle`, `edge_glow`) with measured impact and document recommended fallback order
- [ ] Stage 4.x: Post-baseline LVGL component spike — corner buttons as LVGL button objects using `LV_SYMBOL`; adopt only if p95 frame time and visual latency are equal/better with no touch/parity regressions (Font Awesome deferred unless spike wins)

Stage 4.1 Baseline Snapshot (2026-02-25, robot `192.168.55.201`, target `1000` frames/scenario)
- `idle`: frame_avg `75.12 ms` (`13.31 FPS`), frame_max `80.45 ms`, border_avg `23.01 ms`, effects_avg `17.16 ms`, dirty_px_avg `9600`
- `listening_proxy` (not direct conv_state=2): frame_avg `74.98 ms` (`13.34 FPS`), frame_max `79.65 ms`, border_avg `23.01 ms`, effects_avg `17.09 ms`, dirty_px_avg `9677`
- `thinking_border`: frame_avg `88.51 ms` (`11.30 FPS`), frame_max `99.54 ms`, border_avg `50.62 ms`, dirty_px_avg `9590`
- `talking_energy`: frame_avg `74.28 ms` (`13.46 FPS`), frame_max `91.11 ms`, mouth_avg `19.60 ms`, border_avg `23.41 ms`, dirty_px_avg `9743`
- `rage_effects`: frame_avg `86.53 ms` (`11.56 FPS`), frame_max `88.88 ms`, mouth_avg `30.66 ms`, border_avg `23.10 ms`, dirty_px_avg `9648`
- Findings: all sampled states miss Stage 4 target (`p95 <= 33.3 ms`, `p50 <= 25 ms`) by a wide margin; `thinking_border` is the clearest hotspot (`border_us_avg` ~2.2x idle/listening)
- Findings: `cmd_rx_to_apply_us_avg` is noisy/unreliable in this run (e.g. `thinking_border` outlier); treat as directional until protocol/telemetry validation task is completed
- Finding: listening scenario is currently a proxy because dashboard `/ws` has no direct `face_set_conv_state` command path for forcing LISTENING (`2`)
- Artifact: raw capture saved at `docs/perf/face_stage4_baseline_2026-02-25.json` (generated from `/tmp/face_stage4_baseline.json`)
- [x] Cross-MCU benchmark harness: shared core (`supervisor/api/mcu_benchmark.py`) + face adapter (`mcu_benchmark_face.py`) + reflex adapter (`mcu_benchmark_reflex.py`); p50/p95 per scenario; compare mode (`--compare A B`, <=1% FPS drop gate); WS commands (`mcu_benchmark.start`/`.cancel`), `GET /debug/mcu_benchmark`, CLI (`just mcu-benchmark --target face ...`); 29 unit tests
- [x] Bounded supervisor debug command for direct `SET_CONV_STATE` via WS (`face_set_conv_state` command) — listening/PTT border states can now be benchmarked directly
- [ ] Next: run face benchmark with harness on hardware (p50/p95 capture) and execute telemetry overhead A/B (`--compare` baseline vs `FACE_PERF_TELEMETRY=0`)
- [ ] Next: execute Stage 4.2 in ROI order using this baseline (`thinking_border`/border cache first, then dirty-rect refinement, then transport tuning)
- [ ] Next: reflex MCU benchmark — run `just mcu-benchmark --target reflex` after commissioning Phase 1+ to validate state rate/jitter baselines

Stage 4.2 Border Hotspot A/B Snapshot (2026-02-25, post-cache firmware + updated supervisor)
- Artifacts:
  - baseline: `docs/perf/face_stage4_baseline_2026-02-25.json`
  - post-cache: `docs/perf/face_stage4_post_border_cache_2026-02-25.json`
- `idle`: frame `75.12 -> 58.04 ms` (`-22.7%`), border `23.01 -> 5.98 ms` (`-74.0%`)
- `listening_proxy`: frame `74.98 -> 58.07 ms` (`-22.6%`), border `23.01 -> 5.98 ms` (`-74.0%`)
- `thinking_border`: frame `88.51 -> 51.59 ms` (`-41.7%`), border `50.62 -> 13.86 ms` (`-72.6%`)
- `talking_energy`: frame `74.28 -> 57.19 ms` (`-23.0%`), border `23.41 -> 6.20 ms` (`-73.5%`)
- `rage_effects`: frame `86.53 -> 69.80 ms` (`-19.3%`), border `23.10 -> 6.10 ms` (`-73.6%`)
- Gate check (border tranche): **pass** (`idle border_us_avg <= 8ms`, `thinking border_us_avg <= 20ms`, `thinking frame_us_avg <= 65ms`)
- Remaining gap: overall Stage 4 conversation-frame target still not met (`p95 <= 33.3 ms`, `p50 <= 25 ms`) and p50/p95 collection is still pending

Stage 4.2 Dirty-Rect A/B Snapshot (2026-02-25, post-dirty firmware + updated supervisor)
- Artifact (pre-dirty): `docs/perf/face_stage4_post_border_cache_2026-02-25.json`
- Artifact (post-dirty): `docs/perf/face_stage4_post_dirty_rect_2026-02-25.json`
- `idle`: frame `58.04 -> 44.21 ms` (`-23.8%`), render `5.37 -> 3.64 ms` (`-32.3%`)
- `listening_proxy`: frame `58.07 -> 43.52 ms` (`-25.1%`), render `5.41 -> 3.54 ms` (`-34.5%`)
- `thinking_border`: frame `51.59 -> 51.96 ms` (`+0.7%`), render `4.53 -> 4.55 ms` (`+0.3%`)
- `talking_energy`: frame `57.19 -> 57.23 ms` (`+0.1%`), render `5.24 -> 5.33 ms` (`+1.7%`)
- `rage_effects`: frame `69.80 -> 69.73 ms` (`-0.1%`), render `6.78 -> 6.86 ms` (`+1.2%`)
- Caveat: idle/listening runs are not apples-to-apples with pre-dirty because `effects_us_avg` dropped from ~17k to ~13 (effects/flags mismatch), so those two gains cannot be fully attributed to dirty-rect changes
- Outcome: keep Stage 4.2 dirty-rect task open; rerun A/B with fixed explicit flags before deciding completion

**Evaluation** `[opus]`
- [ ] T1: Automated CI tests (parity check, unit tests, linting)
- [ ] T2: Instrumented benchmarks (frame time, latency, SPI throughput)
- [ ] T3: Developer review — 5 scenarios (idle, conversation, mood sweep, stress, edge cases)
- [ ] T4: Child evaluation protocol (ages 4-6, per eval plan spec)

---

### Personality Engine Implementation

**Spec references**: `specs/personality-engine-spec-stage2.md`, `specs/pe-face-comm-alignment.md`, `specs/face-communication-spec-stage2.md`

**B1–B5 complete** (31 items archived) — L0, PE↔Face compliance, guardrails, schema v2, profile injection, memory, prosody

**B6 — Evaluation** `[opus]`
_2 items complete (B6 test extensions: guardrail/schema/privacy/RS limits) — see archive_
- [ ] PE evaluation checklist: emotional coherence, guardrail compliance, child-safety validation (PE spec S2 §13 + §9 HC/RS) _(automated guardrail tests pass; child-safety T4 is a human protocol — tracked under Face Evaluation)_
- [ ] `[opus]` Reduce baseline talkativeness (currently “talking non-stop”): review specs + annoyance research; set sane defaults (idle/backchannel frequency, cooldowns, auto-followup) + add tests
- [ ] `[sonnet]` Reduce server ping/poll frequency: make requests event-driven + add backoff/debounce so Buddy isn’t “talking non-stop” _(period now configurable + disableable via `planner.plan_period_s` / `planner.enabled` params in dashboard — event-driven still pending)_

---

### Reflex MCU Commissioning

**Prerequisite**: ESP-IDF environment, USB-C cable, hardware on breadboard.

**Phase 1: IMU (BMI270) — Hardware Validation** `[sonnet]`
- [ ] Hardware bring-up: SSH → supervisor logs → `/status` poll → dashboard Telemetry tab → physical tilt/rotate tests
  - Pass criteria: `BMI270 CHIP_ID=0x24 OK`, `INTERNAL_STATUS=0x01`, no `IMU_FAIL` in first 60 s
  - Flat at rest: `accel_z ≈ 1000 mg`, `accel_x ≈ 0`, `gyro_z ≈ 0`
  - Rotate robot ~45°: `gyro_z` deflects, returns to ~0
  - Tilt ~45°: `accel_x` shifts ~700 mg (0.7g)
- [x] Supervisor derived fields: `tilt_angle_deg` + `accel_magnitude_mg` computed in tick loop, serialized in telemetry (17 unit tests pass)
- [x] Dashboard: "IMU Derived" chart (tilt °, accel |g| mg) in TelemetryTab; accel_z sparkline + tilt readout in MonitorTab IMU card
- [ ] Dashboard: CalibrationTab IMU — add a “bubble level” / balance graphic (pitch/roll + `tilt_thresh_deg` overlay) to illustrate what the IMU tuning is doing `[sonnet]`

**Phase 2: Motors + Encoders — Open-Loop Test** `[sonnet]`
- [ ] Enable `BRINGUP_OPEN_LOOP_TEST 1` in `app_main.cpp`
- [ ] Verify motor direction matches encoder count direction (both wheels)
- [ ] Verify encoder counts (1440 counts/rev for TT motor)
- [ ] Disable open-loop test, flash full firmware

**Phase 3: Ultrasonic Range Sensor** `[sonnet]`
- [x] Static distance test (100mm, 300mm, 1000mm, 3000mm ± tolerances) — commissioned 2026-04-22 on HC-SR04 with 1k/2k divider on ECHO→GPIO2; accuracy within datasheet (±3mm perpendicular, ±8mm against angled surfaces); no firmware smoothing needed given 100mm hysteresis band
- [x] OBSTACLE fault triggers at <250mm, clears at >350mm with hysteresis — verified via fault_flags transition (bit 6) while sweeping target past thresholds; 250/350 defaults left as-is until motor/arm geometry is final (runtime-tunable via SET_CONFIG 0x40/0x41)

**Phase 4: E-Stop & Safety Systems** `[sonnet]`
- [ ] E-stop test (GPIO13 switch: open→ESTOP fault, close+CLEAR_FAULTS→recovery)
- [ ] Tilt detection (>45° for >200ms → TILT fault)
- [ ] Command timeout (no commands for 400ms → CMD_TIMEOUT fault + soft-stop)
- [ ] Stall detection (blocked wheel → STALL fault after ~500ms)

**Phase 5: Closed-Loop Integration** `[opus]` for PID tuning
- [ ] PID tuning baseline: SET_TWIST v=100 mm/s, observe convergence
- [ ] Yaw damping: straight-line travel, verify gyro_z correction
- [ ] Full exercise: forward/reverse/spin/arc/stop/accel-limit/obstacle
- [ ] Pass: PID tracks ±20%, no oscillation, safety overrides work under load

**Post-Commissioning** `[sonnet]`
- [ ] ~~Battery voltage sense (ADC) + sag-aware limiting~~ — obsolete. Reflex can't see the real battery with the current topology (AC → Pi → USB → ESP32s). Pi-side `PiPMICMonitor` shipped as Phase 1; Waveshare UPS HAT (B) fuel gauge is queued as Phase 2. See **Power & Battery** section.
- [ ] Odometry integration (x, y, theta) — integrate `w_meas_mrad_s` → heading θ + `v_meas_mm_s` → x/y
- [ ] Gyro-accel complementary filter — supervisor-side; fuse gyro integral + accel correction for stable heading (prerequisite for heading PID)
- [ ] Full IMU heading hold PID (currently gyro damping only; requires complementary filter first)
- [ ] Accel magnitude shock detection — if `accel_magnitude_mg` spikes >2500 mg, emit `SHOCK` event on event bus (collision awareness) `[sonnet]`
- [ ] Motor-IMU correlation diagnostic — dashboard view comparing `gyro_z` vs `w_cmd` to surface motor/encoder faults `[sonnet]`

**Final Solder Prep — Robot Build** `[sonnet]`
Context: single-rail 5V topology per `docs/power.md` (UPS HAT (B) → Pi + ESP32s + TB6612 VM + sensors). Bench testing is done on the dev board; these items are blockers/gotchas before the final robot is soldered up and running untethered.
- [ ] TB6612 VM bulk cap: 1000 µF electrolytic (≥10V, low-ESR) physically adjacent to the VM pin (short leads, ≤20mm trace) to absorb direction-flip sag — per `docs/power.md` §Topology
- [ ] Motor-current wiring gauge: 22AWG minimum / 20AWG preferred on UPS HAT → TB6612 VM and TB6612 → motor leads; breadboard jumpers will sag under ~1.5A peaks
- [ ] HC-SR04 cable routing: twist 5V/GND pair; separate from motor PWM/direction wires to prevent ultrasonic trigger corruption from switching noise
- [x] Free obsolete `PIN_VBAT_SENSE = GPIO_NUM_1` in `esp32-reflex/main/pin_map.h` _(shipped 2026-04-26, `83e204c`)_ — battery telemetry comes from the HAT's INA219 now, not ESP32 ADC.
- [x] Waveshare UPS HAT (B) INA219 monitor (`WaveshareUpsBMonitor`) _(shipped 2026-04-25/26, `9a89368`/`8a0d5d4`)_ — Phase 2 power monitor plan complete; SoC readout, undervoltage warnings, low-battery speech all live.
- [ ] Dev-board motor bring-up: power the breadboard's 5V rail from the UPS HAT (tap Pi header 5V/GND) — validates the power plan and motor driver simultaneously; bench supply @ 5V/≥3A is the backup if Pi isn't nearby

---

### Conversation & Voice

_3 items complete (LLM session memory, TTS resampler hardening, conversation studio session_id fix) — see archive_
- [x] `[sonnet]` Streaming LLM → TTS pipeline (2026-04-18): per-sentence TTS with metadata arriving before audio; cuts first-audio latency ~1–3s on multi-sentence replies. Config flag `llm_stream_enabled` (`RB_LLM_STREAM` env, default on). Pipeline capped at 2 TTS calls/turn (first natural sentence + coalesced continuation). `ConversationResponseV2` schema reordered so `text` is last; new `ConversationStreamParser` extracts metadata from the JSON prefix, sentence-segments the text value, emits `MetadataReady`/`Sentence` events. Supervisor side: `ai_worker` sends zero-length frame as explicit EOS on WS `done`; `tts_worker` idle watchdog bumped 0.8→2.0s as safety net. 28 new tests.
- [x] `[sonnet]` Orpheus prosody-tag fix (2026-04-18): verified via tokenizer probe that `<happy>`, `<excited>`, `<sad>`, `<scared>`, `<angry>`, `<surprised>` are NOT special tokens — they BPE-split and get pronounced as literal speech ("happy happy…" / "excited…" leak). Dropped all fake tags, corrected `silly` → canonical `<laugh>` (was broken `<laughing>`), kept `sleepy` → `<yawn>`. Added `EMOTION_HIGH_INTENSITY_CUES` map that applies real paralinguistic tags (`<chuckle>`/`<gasp>`/`<sigh>`/`<groan>`) only when intensity ≥ per-emotion threshold. `apply_prosody_tag` + `OrpheusTTS.stream/synthesize` now take `intensity` kwarg; threaded through converse batch + live paths. 17 new tests.
- [x] `[sonnet]` TTS ring modulator (2026-04-18): phase-continuous sine multiplication for Dalek-ish robot voice. Off by default (`RB_RING_MOD_HZ=0`); configurable at startup (`RB_RING_MOD_HZ`/`RB_RING_MOD_MIX` env) and at runtime (`tts.cmd.set_ring_mod`). Phase tracked in normalised cycles for sample-accurate continuity across chunk boundaries. 8 tests covering disable paths, phase continuity at 30/50/80 Hz, drift stability, dry/wet mix blend.
- [x] `[sonnet]` Bug: conversation studio chat + PTT not working — envelope deserializer pops `session_id` from payload into header field; AI worker read from payload (always empty); fixed to read `envelope.session_id`; added error events + logging for silent failures
- [x] `[sonnet]` Bug: dashboard text chat replied in `espeak` while supervisor speech used Orpheus — implement conversation priority-1 speech arbitration (preempt in-flight `/tts`; hold planner `say` + suppress speech_policy during active sessions)
- [ ] `[sonnet]` Bug: wake word not working — `--wakeword-model` CLI flag added + ear worker now accepts built-in model names (`alexa`, `hey_jarvis`, etc.); `just download-wakewords` downloads them; test on Pi to confirm pipeline works, then diagnose custom model (threshold? audio device?)
- [ ] `[sonnet]` “Quiet mode” while working: pause deterministic speech-policy comments/backchannels (dashboard toggle; ideally without affecting explicit user-initiated turns)
- [ ] `[opus]` Voice consistency: Buddy’s voice sometimes switches between “male” and “female” — investigate why and make voice selection consistent (pin voice/engine + persist config)
  - [x] Server: pin Orpheus model + voice (`ORPHEUS_VOICE` env var → `tara` default; passed to both legacy + vLLM backends; no model fallback)
  - [x] Unit tests: assert voice is pinned for both Orpheus backends (`server/tests/test_tts_pinning.py`)
  - [ ] Validate on Orpheus: 10+ utterances, no voice drift; then check off parent item
- [ ] `[sonnet]` Wake word model: increase recall from 42%→80%+ (n_samples 15k→50k+, augmentation rounds 3→5, speech-heavy negative data, layer_size 64)
- [ ] `[sonnet]` Wake word: record 20–50 real "hey buddy" utterances from family
- [ ] `[sonnet]` Wake word: soak test 1+ hours idle with household noise
- [x] `[sonnet]` Wake word: pin openWakeWord commit, skip tflite, add `just retrain-wakeword`
- [ ] `[sonnet]` Server VRAM: reduce `ORPHEUS_MAX_NUM_SEQS` 8 → 4. Robot is single-user; current headroom on 3090 Ti is only ~1.6 GB free with Qwen + Orpheus + STT large-v3-turbo all loaded. Expected reclaim ~1 GB. Validate no TTS quality/latency regression.
- [ ] `[sonnet]` Server health: reconcile `orpheus_vram_free_gb` (reports ~14 GB free) vs actual `nvidia-smi` free (~1.6 GB). The health field appears to compute "budget available under cap" rather than measured free memory — rename or add a true `gpu_free_vram_gb` field from an `nvmlDeviceGetMemoryInfo` query so false confidence doesn't mask OOM risk.
- [ ] `[sonnet]` Orpheus lifecycle: under `PERFORMANCE_MODE=1`, Orpheus stays permanently resident — `orpheus_idle_timeout_s=8` never unloads. Either the unload path is broken or `orpheus_min_free_vram_gb=10` is effectively dead config. Audit `server/app/tts/orpheus.py` lifecycle and either fix the unload path or remove the now-misleading config knobs.
- [ ] `[sonnet]` Server: add CUDA OOM alerting in `/health` (or a dedicated `/metrics` endpoint) — surface measured VRAM headroom, recent OOM counts, and a warning flag when free VRAM drops below a threshold (e.g. 512 MB). Belt-and-suspenders now that STT runs on GPU alongside LLM+TTS.

---

### Camera & Vision

- [x] `[sonnet]` Arducam IMX708 integration — validated on-hardware 2026-04-19. Sensor detected by libcamera (imx708 @ 4608×2592, ISP via pisp); supervisor vision worker streams at 640×480 BGR888. Fix was runtime config, not code: supervisor venv had `include-system-site-packages = false` so the apt-installed `python3-picamera2` was invisible — flipped the flag to `true` in `supervisor/.venv/pyvenv.cfg`. Default `vision.hfov_deg=66` is correct for the standard Camera Module 3 lens (75° diagonal ≈ 66° horizontal).
- [x] `[sonnet]` Camera calibration/CV settings in dashboard (HSV + min radius + safety thresholds + /video preview + eyedropper)
- [x] `[sonnet]` Mask editor + camera calibration tooling in dashboard (floor + ball exclusion polygons; persisted to `./data/vision_mask.json`)
- [x] `[sonnet]` Upgrade camera settings for new hardware (camera/ISP params + dashboard UI; Picamera2 controls + rotate/FOV/JPEG quality)

---

### Power & Battery

**Phase 1 (shipped 2026-04-21):** `PowerState` chassis + `PiPMICMonitor` (reads `vcgencmd get_throttled` for undervoltage/throttled bits). Planner prompt + speech_policy own low-battery UX; LLM no longer authors sleepy/nap content. Dashboard `PowerPanel` renders the new state. See `docs/power.md`.

**Phase 2 (shipped 2026-04-26):** Waveshare UPS HAT (B) fuel gauge fully integrated. Pi-side power monitor stack now drives all battery UX; reflex `battery_mv` field retired from the wire.
- [x] `[sonnet]` **WaveshareUpsBMonitor** _(2026-04-25, `9a89368`)_: new `PowerMonitor` subclass in `supervisor/devices/power_monitor.py`. Reads INA219 @ `0x43` over `/dev/i2c-1`; derives charging from current sign, SoC from a piecewise-linear 2S 18650 curve. Auto-detected via I²C probe, composes with `PiPMICMonitor` so PMIC undervoltage stays authoritative. `smbus2 >= 0.4` added; new `--power-monitor=ups-b` mode.
- [x] `[sonnet]` **Pi-side rail voltage via `vcgencmd pmic_read_adc`** _(2026-04-26, `50b4329`)_: tolerant parser pulls `3V3_SYS_V` (proxy for overall rail health) into `PiPMICMonitor.voltage_mv`. Refactored the inline subprocess call into a `_run_vcgencmd()` helper shared by `get_throttled` + `pmic_read_adc`.
- [x] `[sonnet]` **Dashboard chart** _(2026-04-26, `826e61d`)_: `RING_METRICS` now supports dot-paths (`power.voltage_mv`); `MonitorTab` + `TelemetryTab` + `DriveTab` all read the nested key. Thresholds re-tuned for 2S 18650 (8.0 / 7.0 / 6.4 V). `power.soc_pct` and `power.current_ma` also added to the ring set for future sparklines.
- [x] `[sonnet]` **Firmware cleanup** _(2026-04-26, `83e204c`)_: dropped `PIN_VBAT_SENSE` and `battery_mv` from `esp32-reflex/main/{pin_map.h,protocol.h,shared_state.h,telemetry.cpp}` — wire format `<hhhhhhHHHB` → `<hhhhhhHHB` (v1: 21→17 bytes, v2: 27→25 bytes), no version-flag bump (coordinated flash + deploy). Supervisor: dropped `RobotState.battery_mv`, `low_battery_mv` config + tick_loop param, legacy fallback in low-battery emit, mock_reflex / protocol_capture / mcp_tools / dashboard `types.ts` references.
- [x] `[sonnet]` **Safety** _(2026-04-26, `bdcd5ad`)_: `apply_safety` zeroes motion when `0 ≤ power.soc_pct ≤ soc_critical_pct` (gate 4); `state_machine.request_mode` refuses entry into motion modes with reason "battery too low — please charge". Face system mode flips to `LOW_BATTERY` on the same SoC threshold for visual cue. Reflex BROWNOUT remains the hard floor.
- [x] `[sonnet]` **`power.soc_warn_pct` / `power.soc_critical_pct` params** _(2026-04-26, `bdcd5ad`)_: registered with defaults 25 / 10. Wired through `_configure_power_policy_from_registry` into `safety.py` (critical → motion gate) and `PlannerEventBus.set_soc_thresholds` (warn-edge + critical-edge emit `power.low_soc_raised` with severity payload, +5% hysteresis). `SpeechPolicy` keys cooldowns + phrases by severity (`power.low_soc_raised:warn` and `:critical`) so warn doesn't silence critical.
- [x] `[sonnet]` **Session capture** _(confirmed 2026-04-25)_: physical fit check on Pi 5 — went with the GPIO-header variant of UPS HAT (B) instead of the pogo-pin version, which sidesteps the CSI-ribbon clearance risk entirely. Fits cleanly.

**Follow-ups (deferred):** Empirical SoC curve refinement against measured 2S 18650 discharge data — the current waypoints in `_SOC_CURVE` are textbook estimates. Run the pack down once or twice on a real load and adjust waypoints if the kid's experience of "low battery" doesn't line up with reality.

---

### Dashboard

- [ ] `[opus]` **Tuning Studio (expand Face tab; consolidate dashboard; built to complete B6)** — one place to tune face parameters (mouth sync), personality, models, server settings, and the full voice pipeline
  - [x] **Dashboard consolidation (no redundant tuning UI)**
    - [x] Re-scope existing `dashboard/src/tabs/FaceTab.tsx` into “Tuning Studio” (keep tab id `face`; rename tab label to “Tuning”)
    - [x] Keep `Monitor` = health overview, `Protocol` = raw packets, `Params` = param registry; avoid duplicating controls across tabs
    - [x] Fold the previously-planned “Personality engine visualization” into this Studio (no separate dashboard feature)
  - [ ] **Face tuning controls (hardware)**
    - [ ] `[sonnet]` Bug: changing gaze in dashboard Tuning tab does not shift face gaze on device
  - [x] **Tuning Studio layout / UX polish** _(UX review complete; all phases implemented)_
    - [x] `[sonnet]` Phase 1: Two-column face tuning layout — Face Mirror (sticky, left) + scrollable face controls column (Face State, Mood, Gestures, System Mode, Talking, Flags, Manual Lock) on right; CSS grid with `@media` breakpoint at ~1024px collapsing to single-column
    - [x] `[sonnet]` Phase 1: Merge Talking + Flags + Manual Lock into a single "Face Options" card (3 cards → 1)
    - [x] `[sonnet]` Phase 1: Compact gesture grid — 4-column layout with smaller buttons; reduce ~200px to ~120px vertical footprint
    - [x] `[sonnet]` Phase 2: Wrap Server Health, TTS Benchmark, Wake Word Workbench in collapsible `<details>` (default closed); Scenario Runner already collapsible
    - [x] `[sonnet]` Phase 2: Add section group headers — "Face Controls", "Conversation", "Personality", "Diagnostics" — with subtle dividers for visual hierarchy
    - [x] `[sonnet]` Phase 2: Extract FaceTab inline styles → `FaceTab.module.css`; add `:hover`/`:focus` states to buttons
    - [x] `[sonnet]` Phase 3: Conversation Studio restructure — separate inputs from outputs (divider or sub-columns); collapse raw event log behind "Show events" toggle (default closed); group device badges and mute toggles on separate lines
    - [x] `[sonnet]` Phase 3: Move Personality Engine closer to Face Mirror area (immediately after face controls, before diagnostics)
    - [x] `[sonnet]` Phase 4: Sticky Face Mirror in single-column mode (`position: sticky; top: 0`) so it stays visible while scrolling controls
    - [x] `[sonnet]` Phase 4: Wide-viewport 3-column layout at >=1440px (mirror | face controls | personality VA scatter)
    - [x] `[opus]` Phase 4: Evaluate sub-tab navigation — not needed; collapsible diagnostics + two-column layout brings visible content well under 1500px threshold
  - [ ] **Accurate Face Mirror (TypeScript port; protocol-driven)**
    - [x] Phase 1-3: Port core sim to `dashboard/src/face_sim/*` — constants, types, SDF, moods, render (eyes+mouth+sparkles), animation state machine (tweens, spring gaze, blink, breathing, idle wander, talking), protocol bridge (SET_STATE/SET_FLAGS/SET_TALKING/GESTURE/SET_CONV_STATE/SET_SYSTEM → FaceState)
    - [x] `FaceMirrorCanvas.tsx` — 320×240 canvas (2x CSS), 30fps rAF loop, live protocol packet ingestion from useProtocolStore
    - [x] Integrated into FaceTab (Tuning Studio)
    - [x] Supervisor: extend `supervisor/api/protocol_capture.py` to name+decode Face `SET_CONV_STATE (0x25)` (required for border parity)
    - [x] Dashboard: allow protocol WS connection while Studio is open (not only on Protocol tab)
    - [x] Phase 4: Gestures & effects — 20 gesture visual overrides (heart eyes SDF, X-eyes cross, rage shake, sleepy droop, peek-a-boo, shy, dizzy, celebrate, etc.), fire particles, afterglow buffer, holiday effects (birthday/halloween/christmas/new year), snow, confetti, rosy cheeks, system mode animations (boot/shutdown/error/battery/updating)
    - [x] Phase 5: Border renderer — conv-state-driven border (8 states: IDLE/ATTENTION/LISTENING/PTT/THINKING/SPEAKING/ERROR/DONE), border SDF frame + inner glow + attention sweep + thinking orbit dots, corner buttons with 6 icon types, energy sync from talking
    - [x] Phase 6: Mirror modes (Live/Sandbox) + deterministic PRNG toggle + FPS selector (30/60) — sandbox dispatch API, simTime threading, mulberry32 PRNG, breathing dt fix
    - [ ] Phase 7 (deferred): Parity harness — TS face sim may replace Python sim as firmware tuning reference; pin TS sim first, then golden-state pixel-diff suite
  - [x] **Conversation harness (multi-input; addresses Conversation & Voice backlog)**
    - [x] Inputs in one panel: physical PTT, dashboard PTT, wake word, text chat (bypass STT), “simulate wake word” button
    - [x] Fix PTT semantics: PTT OFF = `end_utterance` (no immediate teardown; teardown after response)
    - [x] Multi-turn PTT semantics: keep session open; ACTION cancels session; optional idle timeout ends session
    - [x] Supervisor WS commands: `conversation.start` / `conversation.cancel` / `conversation.end_utterance` / `conversation.send_text`
    - [x] AI worker: add `ai.cmd.send_text` (send `{"type":"text"}` to `/converse`) + handle server `assistant_text` → `ai.conversation.assistant_text`
    - [x] Server `/converse`: always emit `assistant_text` before audio; add client `config` (stream_audio/stream_text/debug); support `stream_audio=false` (true text-only)
  - [x] Add a conversation event stream for Studio (avoid bloating 20 Hz telemetry): per-turn transcript (opt-in), emotion/intensity/mood_reason, gestures, memory_tags, timings, errors
  - [x] **Output modes (two toggles)** — mute speaker playback + no-TTS generation both implemented
  - [x] `[sonnet]` Robot volume control — speaker volume is currently fixed + loud (dashboard slider + persisted setting)
  - [x] `[sonnet]` Bug: Pipeline timeline is blank after sending a chat message (verify `/ws/conversation` + ConversationCapture event wiring)
  - [x] `[sonnet]` Bug: Studio device status indicators wrong (mic DOWN when installed; speaker UP when disconnected)
  - [ ] `[sonnet]` Bug: Conversation Studio shows “conversation disconnected”; typing messages doesn’t work; no events shown
  - [x] `[sonnet]` Conversation Studio UX: filter/search events — type-prefix toggles (tts/personality/ear/ai/conv), search, sort, live/pause; personality OFF by default hides 1Hz snapshot spam
  - [ ] `[sonnet]` Conversation Studio UX: evolve into a chat-style transcript UI (text + voice) while keeping raw events for debugging
  - [x] `[sonnet]` Fault TTS: CMD_TIMEOUT + non-severe faults suppressed from speech policy (only ESTOP/TILT/BROWNOUT speak); IDLE mode speech removed entirely; planner gated when idle_state != "awake" or session_limit_reached
  - [ ] `[sonnet]` Session limit scope: `session_limit_reached` currently appears in every personality snapshot; the flag should only gate conversation starts, not influence personality state broadcasts — decouple the two uses
  - [x] **Voice + latency diagnostics**
    - [x] Pipeline timeline per turn: trigger → VAD end → transcription → emotion → first audio chunk → done (+ error states) — `PipelineTimeline.tsx` component + `/ws/conversation` endpoint + `ConversationCapture` + first_audio/assistant_text events
    - [x] TTS benchmark runner: fixed corpus via `/tts`, time-to-first-byte, total synth time, chunk cadence — `TtsBenchmark.tsx` + `supervisor/api/tts_benchmark.py` + WS commands
    - [x] Full-pipeline timing fields: server emits `stt_latency_ms`/`llm_latency_ms`; supervisor forwards those + `roundtrip_ms` on first audio
    - [x] Conversation benchmark runner (text-mode `/converse`): ws_connect + llm + tts_ttfb + total — `supervisor/api/conv_benchmark.py` + `ConvBenchmark.tsx` + WS command
    - [x] Wake word workbench: live score/threshold view + event log + soak-test summary — `WakeWordWorkbench.tsx` + ear worker score streaming + threshold tuning
  - [x] **Personality tuning + B6 completion harness**
    - [x] Personality visualization: VA scatter plot, mood anchors, mood bar, layer/idle/conv badges, guardrail status + last trigger, RS-1/RS-2 session/daily timers
    - [x] Runtime tuning controls: PE axes sliders (5 params), guardrail toggles (3 bools + 2 time limits), debug impulse injection with presets, param registry integration, WS commands (`personality.override_affect`, `personality.set_guardrail`)
    - [x] **B6 scenario suite inside Studio** (scripted conversations + assertions) — `ScenarioRunner.tsx` + `scenarios.ts`: 6 scenarios (4 mock-only + 2 server-required), clamping/routing/teardown/vocab/limits/privacy, collapsible panel with per-step assertion results
  - [ ] **Future-proofing (models/prompt/server settings + prototyping)**
    - [ ] Versioned “prompt packs” selectable per session (no ad-hoc prompt hacking); show active pack in UI + exports
    - [x] Show planner server `/health` snapshot (model ids, backend, timeouts, GPU budget) inside Studio; include in exports
    - [x] **Model template config visibility + vLLM telemetry (Studio)**
      - [x] Server: expose active model name + resolved chat template kwargs (from `server/app/llm/model_config.py`) via `/health` or `/debug/llm` (include family + kwargs + notes + where applied)
      - [x] Supervisor: ingest server model/template snapshot (poll or push) and surface in Studio + exports (so tuning sessions always include “what model + template”)
      - [x] vLLM metrics: add a lightweight `/debug/vllm` snapshot (queue depth, running/waiting requests, token throughput, KV cache usage, GPU mem/util if available) + show in Studio
    - [x] Optional dev-only per-session generation overrides (temperature/max_output_tokens) for fast experiments
  - [ ] **Record / replay / export (diagnose + share + regressions)**
    - [ ] Define `TuningSession.v1` export schema: config snapshots, per-turn messages/metadata, protocol slice, timings/errors
    - [ ] “Record session” (opt-in; default off) + export bundle + replay bundle (offline debugging)
  - [ ] **Deterministic behavior harness (capture + modify + replay) — keep PE + comm tuning reproducible in one place**
    - [ ] Define a “determinism contract”: which subsystems must be deterministic given the same inputs (PE L0, speech policy, conv_state, mood sequencer) + list sources of nondeterminism (LLM/STT/TTS, random backchannel, idle wander)
    - [ ] Studio “Sandbox” mode: apply *temporary* overrides (PE axes/guardrails, speech policy toggles, conv_state timings, face params) without changing prod defaults; export overrides with the session
    - [ ] Deterministic seed controls: make all Studio randomness seedable (face sim, conv_state backchannel scheduling) and always include seed(s) in exports
    - [ ] Replay runner: re-run deterministic subsystems from a recorded session (inputs/events) and diff outputs (face TX stream, PE snapshot, guardrail triggers, speech intents)
    - [ ] Diff UI: show before/after timelines + packet diffs to validate tuning changes quickly
  - [ ] **Recipes + Codex-friendly skills**
    - [ ] Declarative tuning recipe runner (YAML/JSON): set toggles/config → run turns (text/audio) → assertions → export
    - [ ] Supervisor HTTP: list recipes / run recipe (stream progress) / fetch bundles
    - [ ] Add a Codex CLI skill to list/run recipes and summarize failures from exported bundles

---

## Completed

_138 items archived to `docs/TODO-archive.md` (latest: 2026-02-24). Sections: Face specs, PE L0, Dashboard, IMU, PE B1b–B5, Face Sim V3, Stage 4.0, Face phases 0–5, Timestamps, Infrastructure, B6 tests, Conversation & Voice, Camera settings._

---

## Future Development & R&D

### Near-Term Ideas
- `[opus]` Speaker personalization (HC-2 compliant): explicit per-child profiles via parent UI; no voice ID / biometric embeddings
- Home Assistant light control via conversation (see `docs/home-assistant-integration.md`)
- Additional modes: LINE_FOLLOW, BALL, CRANE, CHARGING

### Blue-Sky Personality Features
- `[opus]` Homeostatic drives layer (energy/curiosity/social “batteries”) that slowly biases PE impulses over minutes
- `[opus]` Rituals & routines library: parent-scheduled “morning / bedtime / homework” scripts with safe affect arcs
- `[opus]` Curiosity threads (“quests”): bounded follow-ups based on `memory_tags` with decay + consent gate
- `[opus]` Social repair skills: apologize, clarify misunderstandings, de-escalate, and re-engage after frustration
- `[opus]` Story mode: short interactive stories with `emotional_arc` + gestures + prosody (bounded + opt-out)
- `[opus]` Humor timing engine: callbacks, playful patterns, and “inside jokes” without parasocial deepening
- `[opus]` Embodied habits: micro-motions / gaze cues synced to PE mood + sensor context (with strict safety caps)
- `[opus]` Parent-tunable “persona packs”: seasonal themes, catchphrases, preferred activities (opt-in + reversible)

### R&D Research Plan
- On-device inference feasibility if PE spec revisits PE-7 decision
- Advanced wake word models (transformer-based, multi-keyword)
- Multi-modal interaction (gesture recognition via camera + IMU fusion)
- Proactive behavior triggers from sensor patterns (per bucket-4 research)

### Ongoing Research Cadence
- Monthly spec review: check assumptions against upstream model releases (Qwen, Orpheus)
- Track ESP-IDF updates for display pipeline improvements
- Monitor child-robot interaction research for safety/ethical updates

---

## Model Assignment Guide

| Task Type | Model | Rationale |
| --- | --- | --- |
| Spec writing & interpretation | Opus 4.6 | Requires deep understanding of multi-document specs |
| Architecture decisions | Opus 4.6 | Trade-off analysis, system-level reasoning |
| Complex debugging | Opus 4.6 | Multi-system causality tracing |
| Personality engine design | Opus 4.6 | Psychology-informed design, prompt engineering |
| PID tuning & control theory | Opus 4.6 | Mathematical reasoning, parameter sensitivity |
| Mechanical refactors | Sonnet 4.6 | Pattern-apply across files (rename, import updates) |
| Test writing | Sonnet 4.6 | Well-scoped, pattern-following |
| README/doc updates | Sonnet 4.6 | Factual updates, no design decisions |
| Parity checks | Sonnet 4.6 | Systematic comparison, no judgment calls |
| Protocol documentation | Sonnet 4.6 | Transcribe from code to docs |
| Linter/config fixes | Sonnet 4.6 | Mechanical, well-defined |

---

## Efficiency Notes

### Token optimization
- **Spec navigation**: Use `specs/INDEX.md` (once created) for targeted reading instead of re-reading full 1000+ line specs
- **Key file paths**: Common edit targets are listed in CLAUDE.md under Repository Structure
- **Debug cycles**: Use `/diagnose` skill (once created) to debug MCUs directly from dev PC, avoiding Pi SSH round-trips

### Process improvements
- **Spec-first**: Never implement counter to a spec without debating the spec change first
- **Parity checks**: Run `just check-parity` after any face constant changes
- **Preflight**: Run `just preflight` before any commit (lint + test + parity)

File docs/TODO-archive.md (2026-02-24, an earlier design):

# Robot Buddy — TODO Archive

Completed items moved from `docs/TODO.md` during periodic compaction.
This file is not loaded into Claude Code context. See `docs/TODO.md` for active work.

---

## Archived 2026-02-24

### Personality Engine — B6 Evaluation (tests)
- [x] Add/extend tests: clamping behavior, worker intensity caps, planner-emote impulse routing, conv-ended teardown coverage, `confused` server vocab, schema-v2 parsing, guided decoding compliance
- [x] Add tests for RS-1/RS-2 time limits, `/converse` overflow/timeouts/disconnects, and "no transcript logs by default" privacy policy

### Conversation & Voice
- [x] `[opus]` LLM conversation history/memory — server-side session context (stash/restore with 30 min TTL)
- [x] `[sonnet]` TTS perf hardening: replace Python-loop resampling in `server/app/tts/orpheus.py` with an efficient resampler; add max utterance duration safeguards

### Dashboard
- [x] `[sonnet]` Camera settings panel

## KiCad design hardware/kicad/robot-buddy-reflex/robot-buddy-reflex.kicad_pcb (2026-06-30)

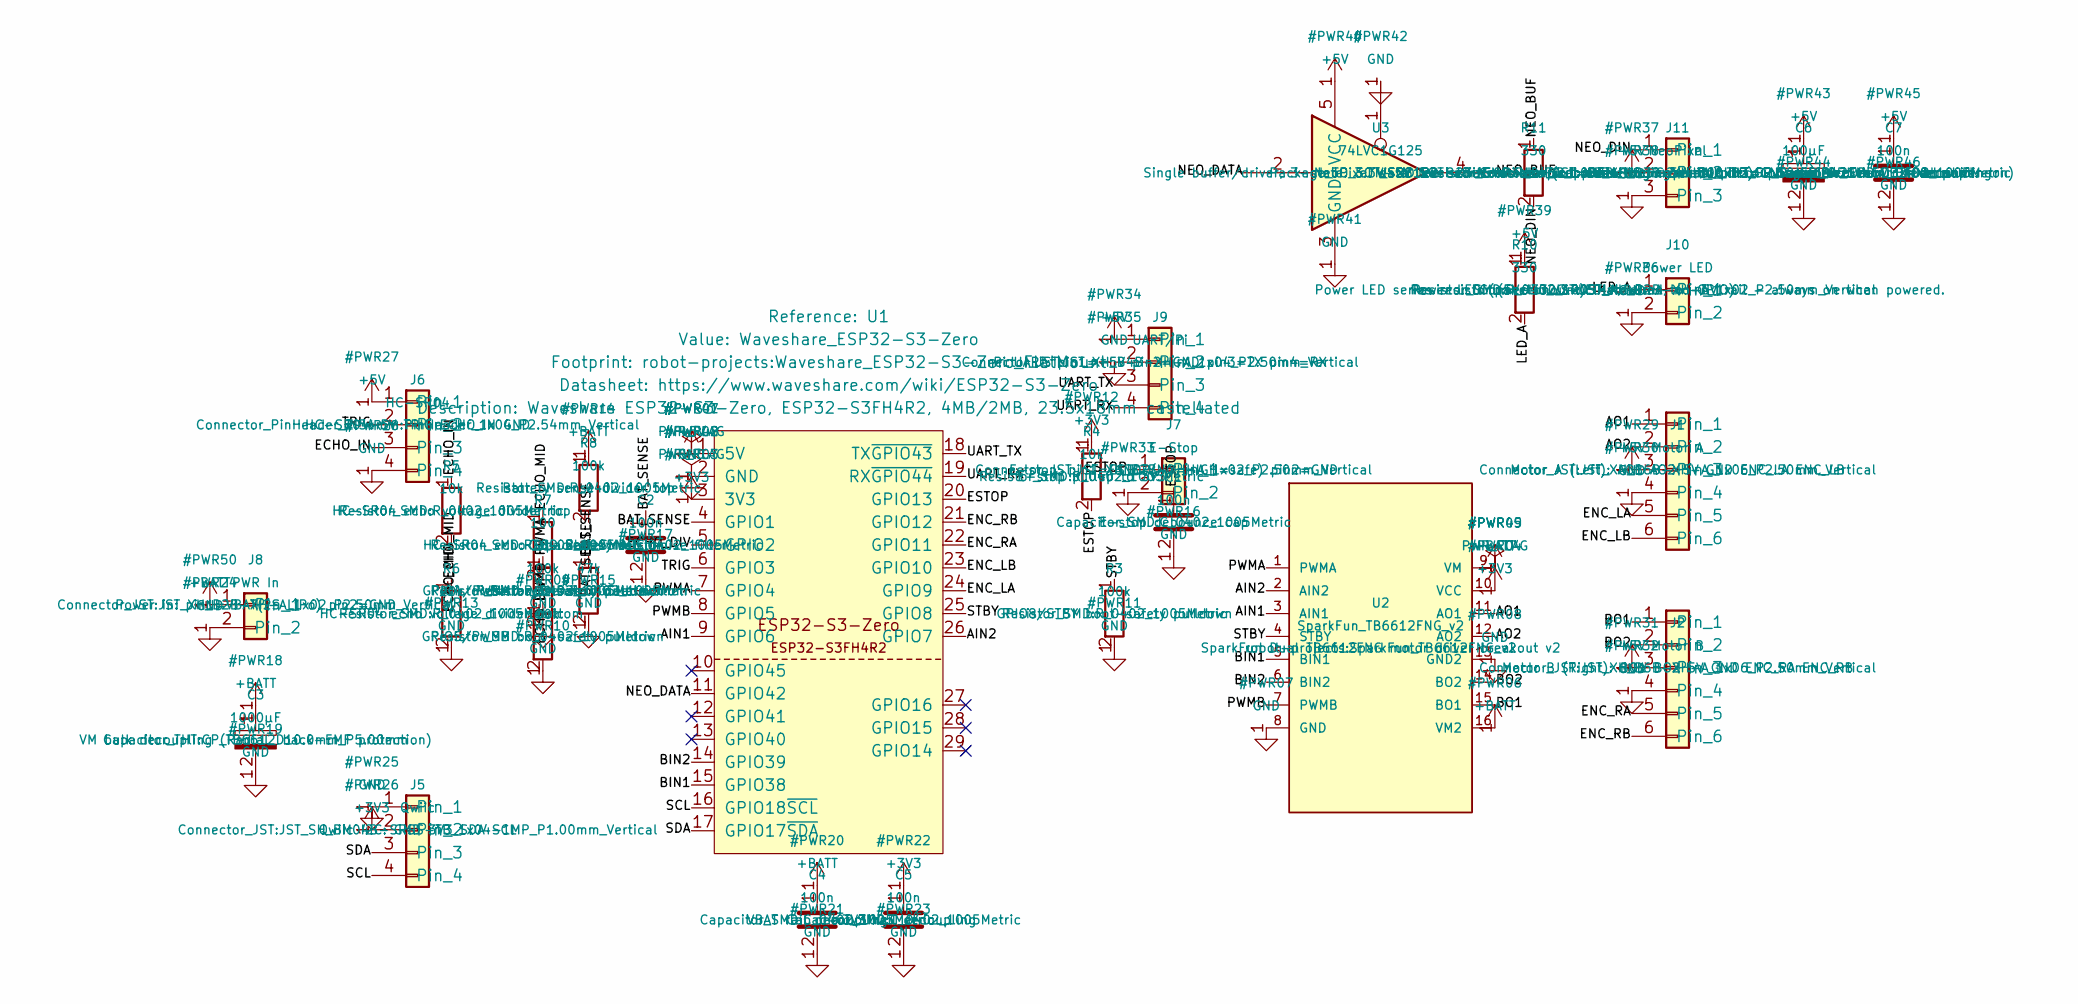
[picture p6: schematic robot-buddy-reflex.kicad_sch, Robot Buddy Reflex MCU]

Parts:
C1, C2, C4, C5, C7: 100n; C_0402_1005Metric
C3: 1000µF; CP_Radial_D10.0mm_P5.00mm
C6: 100µF; CP_Radial_D5.0mm_P2.00mm
J1: Motor A; JST_XH_B6B-XH-A_1x06_P2.50mm_Vertical
J2: Motor B; JST_XH_B6B-XH-A_1x06_P2.50mm_Vertical
J5: Qwiic; JST_SH_BM04B-SRSS-TB_1x04-1MP_P1.00mm_Vertical
J6: HC-SR04; PinHeader_1x04_P2.54mm_Vertical
J7: E-Stop; JST_XH_B2B-XH-A_1x02_P2.50mm_Vertical
J8: PWR In; JST_XH_B2B-XH-A_1x02_P2.50mm_Vertical
J9: UART/Pi; JST_XH_B4B-XH-A_1x04_P2.50mm_Vertical
J10: Power LED; JST_XH_B2B-XH-A_1x02_P2.50mm_Vertical
J11: NeoPixel; JST_XH_B3B-XH-A_1x03_P2.50mm_Vertical
R1, R2, R3, R8: 100k; R_0402_1005Metric
R4, R5: 10k; R_0402_1005Metric
R6: 20k; R_0402_1005Metric
R7: 100; R_0402_1005Metric
R9: 47k; R_0402_1005Metric
R10, R11: 330; R_0402_1005Metric
U1: Waveshare_ESP32-S3-Zero; Waveshare_ESP32-S3-Zero_FlatMount
U2: SparkFun_TB6612FNG_v2
U3: 74LVC1G125; SOT-23-5

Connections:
+3V3: C5.1, J5.2, R4.1, U1.3 (3V3), U2.10 (VCC)
/AIN1: U1.9 (GPIO6), U2.3 (AIN1)
/AIN2: U1.26 (GPIO7), U2.2 (AIN2)
/AO1: J1.1, U2.11 (AO1)
/AO2: J1.2, U2.12 (AO2)
/BAT_SENSE: C2.1, R8.2, R9.1, U1.4 (GPIO1)
/BIN1: U1.15 (GPIO38), U2.5 (BIN1)
/BIN2: U1.14 (GPIO39), U2.6 (BIN2)
/BO1: J2.1, U2.15 (BO1)
/BO2: J2.2, U2.14 (BO2)
/ECHO_DIV: R7.2, U1.5 (GPIO2)
/ECHO_IN: J6.3, R5.1
/ECHO_MID: R5.2, R6.1, R7.1
/ENC_LA: J1.5, U1.24 (GPIO9)
/ENC_LB: J1.6, U1.23 (GPIO10)
/ENC_RA: J2.5, U1.22 (GPIO11)
/ENC_RB: J2.6, U1.21 (GPIO12)
/ESTOP: C1.1, J7.1, R4.2, U1.20 (GPIO13)
/LED_A: J10.1, R10.2
/NEO_BUF: R11.1, U3.4
/NEO_DATA: U1.11 (GPIO42), U3.2
/NEO_DIN: J11.1, R11.2
/PWMA: R1.1, U1.7 (GPIO4), U2.1 (PWMA)
/PWMB: R2.1, U1.8 (GPIO5), U2.7 (PWMB)
/SCL: J5.4, U1.16 (GPIO18~SCL)
/SDA: J5.3, U1.17 (GPIO17~SDA)
/STBY: R3.1, U1.25 (GPIO8), U2.4 (STBY)
/TRIG: J6.2, U1.6 (GPIO3)
/UART_RX: J9.4, U1.19 (RX~GPIO44)
/UART_TX: J9.3, U1.18 (TX~GPIO43)

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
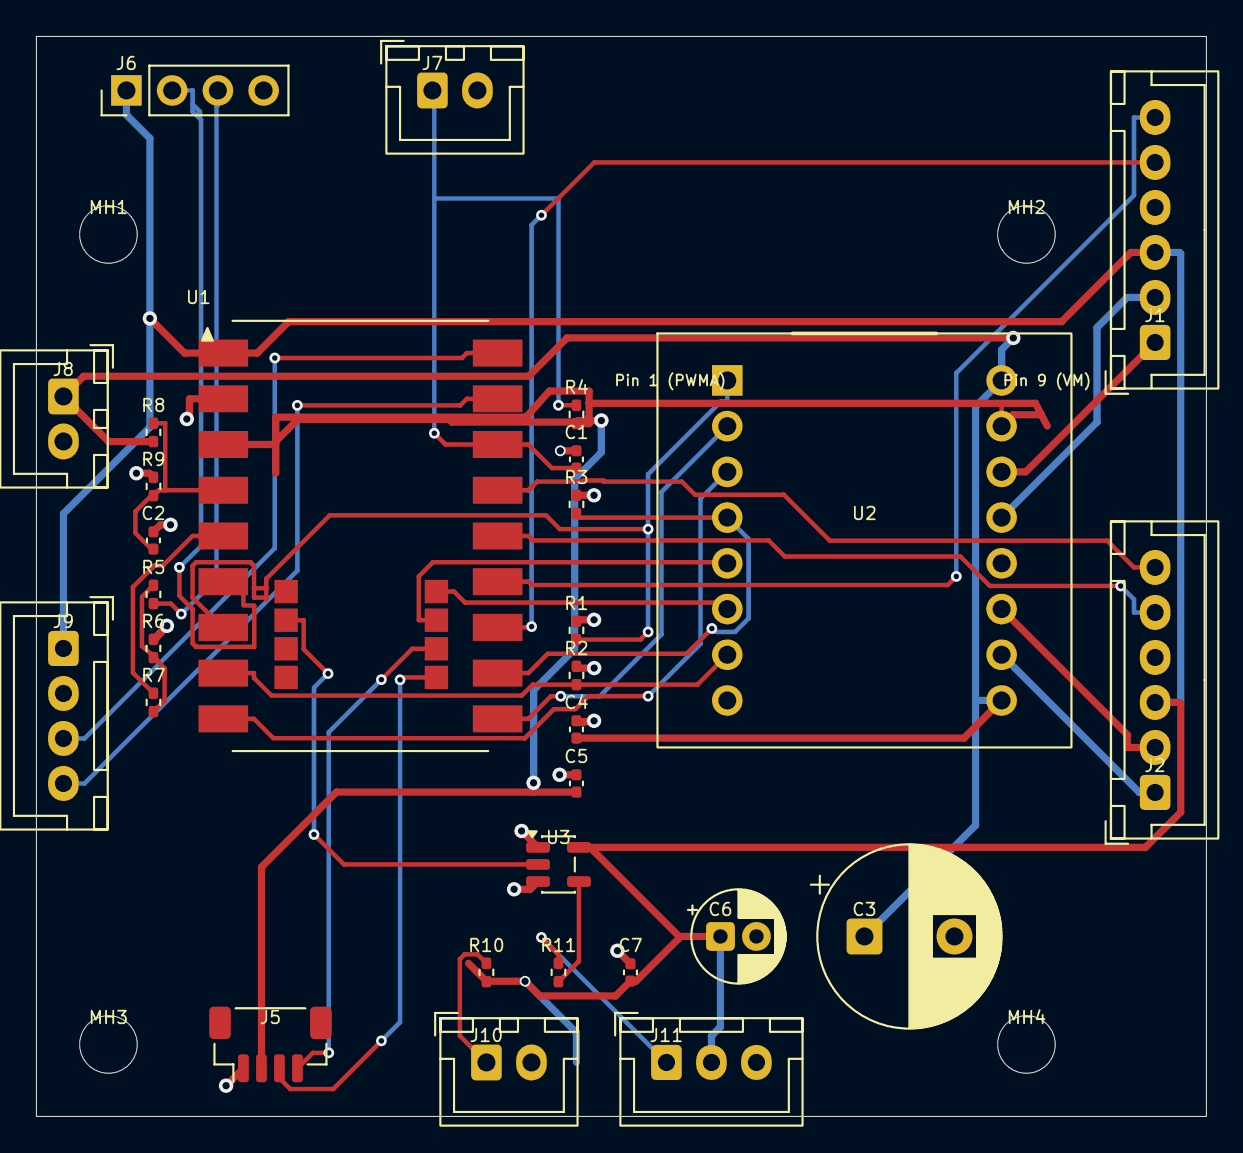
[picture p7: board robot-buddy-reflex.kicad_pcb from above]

Board: 4 copper layers, 65.0 x 60.0 mm, 34 parts (0 on the bottom side), 33 nets.

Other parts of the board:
MH1, MH2, MH3, MH4: MountingHole; MountingHole_3.2mm_M3_DIN965

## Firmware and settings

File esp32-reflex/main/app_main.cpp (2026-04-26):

// Reflex MCU — app_main
// Full system: motor + encoder + IMU + protocol + control loop + safety.

#include "freertos/FreeRTOS.h"
#include "freertos/task.h"
#include "esp_log.h"
#include "esp_timer.h"

#include "config.h"
#include "pin_map.h"
#include "motor.h"
#include "encoder.h"
#include "imu.h"
#include "range_ultrasonic.h"
#include "control.h"
#include "safety.h"
#include "usb_rx.h"
#include "telemetry.h"
#include "shared_state.h"
#include "protocol.h"

#include "driver/usb_serial_jtag.h"
#include <cstring>

static const char* TAG = "reflex";

// ---- Global shared state (owned here, extern'd in shared_state.h) ----
ImuBuffer             g_imu;
CommandBuffer         g_cmd;
RangeBuffer           g_range;
TelemetryState        g_telemetry;
std::atomic<uint16_t> g_fault_flags{0};
std::atomic<uint32_t> g_cmd_seq_last{0};

// ============================================================
// Bring-up test: open-loop motor ramp + encoder readback.
// Set to 0 once closed-loop control is validated.
// When enabled, control_task and safety_task are NOT started.
// ============================================================
#define BRINGUP_OPEN_LOOP_TEST 1

#if BRINGUP_OPEN_LOOP_TEST

// Emit a BRINGUP_DIAG telemetry packet with the current encoder snapshot.
// Best-effort, non-blocking — drop on TX backpressure (matches telemetry_task).
// ESP_LOGI calls in this task are silenced (binary protocol owns USB-Serial-JTAG);
// this packet is the actual data path the supervisor consumes.
static void emit_bringup_diag(BringupPhase phase, MotorSide side, bool forward, uint16_t pwm_duty)
{
    int32_t cur_l, cur_r;
    encoder_snapshot(&cur_l, &cur_r);

    BringupDiagPayload p{};
    p.phase = static_cast<uint8_t>(phase);
    p.side = (side == MotorSide::LEFT) ? 0u : 1u;
    p.forward = forward ? 1u : 0u;
    p.pwm_duty = pwm_duty;
    p.raw_l = cur_l;
    p.raw_r = cur_r;

    uint8_t      wire_buf[64];
    const size_t wire_len = packet_build_v2(
        static_cast<uint8_t>(TelId::BRINGUP_DIAG), next_seq(), static_cast<uint64_t>(esp_timer_get_time()),
        reinterpret_cast<const uint8_t*>(&p), sizeof(p), wire_buf, sizeof(wire_buf));
    if (wire_len == 0) return;
    usb_serial_jtag_write_bytes(reinterpret_cast<const char*>(wire_buf), wire_len, 0);
}

static void open_loop_test_task(void* arg)
{
    ESP_LOGI(TAG, "=== OPEN-LOOP BRING-UP TEST ===");
    ESP_LOGI(TAG, "Will ramp each motor forward then reverse.");
    ESP_LOGI(TAG, "Watch encoder counts — they should increase with positive PWM.");

    vTaskDelay(pdMS_TO_TICKS(2000));

    motor_enable();

    const uint16_t test_duty = g_cfg.max_pwm / 4;
    const uint32_t hold_ms = 1500;
    const uint32_t sample_interval_ms = 100;

    auto run_phase = [&](const char* label, BringupPhase phase, MotorSide side, bool forward) {
        ESP_LOGI(TAG, "--- %s ---", label);

        int32_t start_l, start_r;
        encoder_snapshot(&start_l, &start_r);

        motor_set_output(side, test_duty, forward);
        uint32_t elapsed = 0;
        while (elapsed < hold_ms) {
            vTaskDelay(pdMS_TO_TICKS(sample_interval_ms));
            elapsed += sample_interval_ms;

            int32_t cur_l, cur_r;
            encoder_snapshot(&cur_l, &cur_r);
            ESP_LOGI(TAG, "  enc L=%ld  R=%ld  (dL=%ld dR=%ld)", (long)cur_l, (long)cur_r, (long)(cur_l - start_l),
                     (long)(cur_r - start_r));
            emit_bringup_diag(phase, side, forward, test_duty);
        }

        motor_set_output(side, 0, true);
        motor_brake();
        vTaskDelay(pdMS_TO_TICKS(500));
        emit_bringup_diag(BringupPhase::IDLE, side, forward, 0);
    };

    run_phase("LEFT FORWARD", BringupPhase::LEFT_FWD, MotorSide::LEFT, true);
    run_phase("LEFT REVERSE", BringupPhase::LEFT_REV, MotorSide::LEFT, false);
    run_phase("RIGHT FORWARD", BringupPhase::RIGHT_FWD, MotorSide::RIGHT, true);
    run_phase("RIGHT REVERSE", BringupPhase::RIGHT_REV, MotorSide::RIGHT, false);

    motor_hard_kill();
    ESP_LOGI(TAG, "=== OPEN-LOOP TEST COMPLETE ===");
    ESP_LOGI(TAG, "Check: positive PWM should give positive encoder delta.");
    ESP_LOGI(TAG, "If a motor is backwards, swap its encoder A/B or direction pins in pin_map.h.");

    vTaskDelete(nullptr);
}

#endif // BRINGUP_OPEN_LOOP_TEST

extern "C" void app_main()
{
    // Silence ALL ESP_LOG immediately — USB Serial/JTAG is used exclusively
    // for binary protocol.  Any text output corrupts COBS framing.
    esp_log_level_set("*", ESP_LOG_NONE);

    // ---- Phase 1: hardware init ----
    motor_init();
    encoder_init();

    if (imu_init()) {
        ESP_LOGI(TAG, "IMU initialized OK");
        // imu_task on PRO core (core 0), below control_task priority
        xTaskCreatePinnedToCore(imu_task, "imu", 4096, nullptr, 8, nullptr, 0);
    } else {
        ESP_LOGE(TAG, "IMU init FAILED — continuing without gyro");
        g_fault_flags.store(static_cast<uint16_t>(Fault::IMU_FAIL), std::memory_order_relaxed);
    }

    if (range_init()) {
        ESP_LOGI(TAG, "Range sensor initialized OK");
    } else {
        ESP_LOGW(TAG, "Range sensor init failed — continuing without range");
    }

    // Install USB Serial/JTAG driver before starting tasks that use it.
    usb_serial_jtag_driver_config_t usb_cfg = {};
    usb_cfg.rx_buffer_size = 512;
    usb_cfg.tx_buffer_size = 512;
    ESP_ERROR_CHECK(usb_serial_jtag_driver_install(&usb_cfg));

    // ---- Phase 2: APP core tasks (USB protocol + telemetry + range) ----
    xTaskCreatePinnedToCore(usb_rx_task, "usb_rx", 4096, nullptr, 5, nullptr, 1);   // APP core, normal priority
    xTaskCreatePinnedToCore(telemetry_task, "telem", 4096, nullptr, 3, nullptr, 1); // APP core, below-normal
    xTaskCreatePinnedToCore(range_task, "range", 3072, nullptr, 4, nullptr, 1); // APP core, between usb_rx and telem

#if BRINGUP_OPEN_LOOP_TEST
    xTaskCreatePinnedToCore(open_loop_test_task, "ol_test", 4096, nullptr, 5, nullptr, 1);
#else
    // ---- Phase 3: PRO core tasks (control + safety) ----
    // Enable motors — safety_task will gate them on faults.
    motor_enable();

    xTaskCreatePinnedToCore(control_task, "control", 4096, nullptr, 10, nullptr, 0); // PRO core, highest
    xTaskCreatePinnedToCore(safety_task, "safety", 4096, nullptr, 6, nullptr, 0);    // PRO core, above-normal
#endif
}

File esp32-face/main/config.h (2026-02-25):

#pragma once
#include <cstdint>
#include <cmath>
#include <cstddef>

// ---- Display (landscape) ----
constexpr int SCREEN_W = 320;
constexpr int SCREEN_H = 240;
constexpr int SPI_FREQ_HZ = 40'000'000; // 40 MHz SPI clock

// ---- Face geometry (LVGL coordinates, 320x240 landscape) ----

constexpr float EYE_WIDTH = 80.0f;
constexpr float EYE_HEIGHT = 85.0f;
constexpr float EYE_CORNER_R = 25.0f;
constexpr float PUPIL_R = 20.0f;

constexpr float LEFT_EYE_CX = 90.0f;
constexpr float LEFT_EYE_CY = 85.0f;
constexpr float RIGHT_EYE_CX = 230.0f;
constexpr float RIGHT_EYE_CY = 85.0f;

constexpr float GAZE_EYE_SHIFT = 3.0f;   // eye body shift per unit gaze
constexpr float GAZE_PUPIL_SHIFT = 8.0f; // pupil shift per unit gaze
constexpr float MAX_GAZE = 12.0f;

// ---- Mouth geometry ----
constexpr float MOUTH_CX = 160.0f;
constexpr float MOUTH_CY = 185.0f;
constexpr float MOUTH_HALF_W = 60.0f;
constexpr float MOUTH_THICKNESS = 8.0f;
constexpr float HEART_SOLID_SCALE = 1.0f; // sim parity: full-eye heart scale factor
constexpr float HEART_PUPIL_SCALE = 2.5f; // sim parity: pupil heart scale factor

// ---- Timing ----
constexpr int   ANIM_FPS = 30;          // TFT refresh, 30 FPS is sufficient
constexpr float BLINK_INTERVAL = 2.0f;  // base seconds between blinks
constexpr float BLINK_VARIATION = 3.0f; // random extra seconds
constexpr float IDLE_INTERVAL = 1.5f;
constexpr float IDLE_VARIATION = 2.5f;
constexpr float BREATH_SPEED = 1.8f;   // rad/s
constexpr float BREATH_AMOUNT = 0.04f; // ±4% scale (subtler than LED)

// ---- Brightness ----
constexpr uint8_t DEFAULT_BRIGHTNESS = 200; // TFT backlight (0-255 via LEDC)

// ---- UI controls (discreet corner icons) ----
constexpr int     UI_ICON_DIAMETER = 32;     // visible icon button size
constexpr int     UI_ICON_HITBOX = 40;       // interactive touch target
constexpr int     UI_ICON_MARGIN = 8;        // edge inset
constexpr uint8_t UI_ICON_IDLE_OPA = 140;    // ~55%
constexpr uint8_t UI_ICON_PRESSED_OPA = 217; // ~85%

// ---- System overlay FX toggles ----
// Performance fallback order (disable first -> last): GLITCH, VIGNETTE, SCANLINES.
constexpr bool SYSTEM_FX_SCANLINES = true;
constexpr bool SYSTEM_FX_VIGNETTE = true;
constexpr bool SYSTEM_FX_GLITCH = true;

// ---- Runtime diagnostics ----
constexpr uint32_t FRAME_TIME_LOG_INTERVAL_MS = 5000;
constexpr bool     FACE_PERF_TELEMETRY = true;
constexpr uint8_t  FACE_PERF_SAMPLE_DIV = 8;
constexpr bool     FACE_DIRTY_RECT = true;
constexpr uint8_t  FACE_AFTERGLOW_DOWNSAMPLE = 2;

// ---- Telemetry ----
constexpr int TELEMETRY_HZ = 20;

// ---- Calibration mode (temporary for ES3C28P mapping) ----
constexpr bool        FACE_CALIBRATION_MODE = false;
constexpr uint32_t    CALIB_TOUCH_AUTOCYCLE_MS = 0;
constexpr std::size_t CALIB_TOUCH_DEFAULT_INDEX = 3;

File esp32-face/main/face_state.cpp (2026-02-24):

#include "face_state.h"

#include "esp_timer.h"

#include <cmath>
#include <cstdlib>
#include <initializer_list>

static float now_s()
{
    return static_cast<float>(esp_timer_get_time()) / 1'000'000.0f;
}

static float randf()
{
    return static_cast<float>(rand()) / static_cast<float>(RAND_MAX);
}

static float randf_range(float lo, float hi)
{
    return lo + randf() * (hi - lo);
}

static float clampf(float v, float lo, float hi)
{
    if (v < lo) return lo;
    if (v > hi) return hi;
    return v;
}

static float tween(float current, float target, float speed)
{
    return current + (target - current) * speed;
}

static float spring_step(float current, float target, float& vel, float k = 0.25f, float d = 0.65f)
{
    const float force = (target - current) * k;
    vel = (vel + force) * d;
    return current + vel;
}

static void clear_sparkles(FaceState& fs)
{
    for (auto& px : fs.fx.sparkle_pixels) {
        px.active = false;
        px.life = 0;
    }
}

static void clear_fire(FaceState& fs)
{
    for (auto& px : fs.fx.fire_pixels) {
        px.active = false;
        px.life = 0.0f;
    }
}

static void set_active_gesture(FaceState& fs, GestureId gesture, float duration_s, float now)
{
    fs.active_gesture = static_cast<uint8_t>(gesture);
    fs.active_gesture_until = now + clampf(duration_s, 0.08f, 10.0f);
}

static void update_boot(FaceState& fs)
{
    const float now = now_s();
    const float elapsed = now - fs.fx.boot_timer;

    if (fs.fx.boot_phase == 0) {
        const float progress = fminf(1.0f, elapsed / 1.0f);
        const float eased = 1.0f - (1.0f - progress) * (1.0f - progress);
        fs.eye_l.openness = eased;
        fs.eye_r.openness = eased;
        fs.eye_l.openness_target = eased;
        fs.eye_r.openness_target = eased;
        if (progress >= 1.0f) {
            fs.fx.boot_phase = 1;
            fs.fx.boot_timer = now;
        }
        return;
    }

    if (fs.fx.boot_phase == 1) {
        if (elapsed < 0.3f) {
            const float t = elapsed / 0.3f;
            fs.eye_l.openness = 1.0f - t;
            fs.eye_r.openness = 1.0f - t;
        } else if (elapsed < 0.5f) {
            fs.eye_l.openness = 0.0f;
            fs.eye_r.openness = 0.0f;
        } else if (elapsed < 0.9f) {
            const float t = (elapsed - 0.5f) / 0.4f;
            fs.eye_l.openness = t;
            fs.eye_r.openness = t;
        } else {
            fs.eye_l.openness = 1.0f;
            fs.eye_r.openness = 1.0f;
            fs.eye_l.openness_target = 1.0f;
            fs.eye_r.openness_target = 1.0f;
            fs.fx.boot_phase = 2;
            fs.fx.boot_timer = now;
        }
        return;
    }

    if (fs.fx.boot_phase == 2) {
        float gx = 0.0f;
        if (elapsed < 0.5f) {
            gx = -2.0f * (elapsed / 0.5f);
        } else if (elapsed < 1.2f) {
            gx = -2.0f + 4.0f * ((elapsed - 0.5f) / 0.7f);
        } else if (elapsed < 1.8f) {
            gx = 2.0f * (1.0f - (elapsed - 1.2f) / 0.6f);
        } else {
            gx = 0.0f;
            fs.fx.boot_active = false;
        }
        fs.eye_l.gaze_x = gx;
        fs.eye_l.gaze_x_target = gx;
        fs.eye_l.gaze_y = 0.0f;
        fs.eye_l.gaze_y_target = 0.0f;
        fs.eye_r.gaze_x = gx;
        fs.eye_r.gaze_x_target = gx;
        fs.eye_r.gaze_y = 0.0f;
        fs.eye_r.gaze_y_target = 0.0f;
    }
}

static void update_breathing(FaceState& fs)
{
    if (!fs.fx.breathing) {
        return;
    }
    fs.fx.breath_phase += fs.fx.breath_speed / static_cast<float>(ANIM_FPS);
    const float two_pi = 2.0f * static_cast<float>(M_PI);
    if (fs.fx.breath_phase > two_pi) {
        fs.fx.breath_phase -= two_pi;
    }
}

static void update_sparkle(FaceState& fs)
{
    if (!fs.fx.sparkle) {
        clear_sparkles(fs);
        return;
    }

    for (auto& px : fs.fx.sparkle_pixels) {
        if (!px.active) {
            continue;
        }
        if (px.life > 0) {
            px.life--;
        }
        if (px.life == 0) {
            px.active = false;
        }
    }

    if (randf() >= fs.fx.sparkle_chance) {
        return;
    }

    for (auto& px : fs.fx.sparkle_pixels) {
        if (px.active) {
            continue;
        }
        px.active = true;
        px.x = static_cast<int16_t>(rand() % SCREEN_W);
        px.y = static_cast<int16_t>(rand() % SCREEN_H);
        px.life = static_cast<uint8_t>(5 + (rand() % 11));
        break;
    }
}

static void update_fire(FaceState& fs)
{
    if (!fs.anim.rage) {
        clear_fire(fs);
        return;
    }

    for (auto& px : fs.fx.fire_pixels) {
        if (!px.active) {
            continue;
        }
        px.x += randf_range(-1.5f, 1.5f);
        px.y -= 3.0f;
        px.life -= 1.0f;
        px.heat *= 0.9f;
        if (px.life <= 1.0f || px.y < 0.0f) {
            px.active = false;
        }
    }

    if (randf() >= 0.3f) {
        return;
    }

    for (float cx : {LEFT_EYE_CX, RIGHT_EYE_CX}) {
        for (auto& px : fs.fx.fire_pixels) {
            if (px.active) {
                continue;
            }
            px.active = true;
            px.x = cx + randf_range(-20.0f, 20.0f);
            px.y = LEFT_EYE_CY - 30.0f;
            px.life = static_cast<float>(5 + (rand() % 11));
            px.heat = 1.0f;
            break;
        }
    }
}

static bool update_system(FaceState& fs)
{
    return fs.system.mode != SystemMode::NONE;
}
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

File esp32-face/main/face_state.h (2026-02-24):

#pragma once
// Face animation state machine for TFT renderer.
// Behavior is aligned with tools/face_state_v2.py.

#include "config.h"
#include <cstdint>

// ---- Enums ----

enum class Mood : uint8_t {
    NEUTRAL = 0,   // calm, attentive default
    HAPPY = 1,     // pleased, upturned eyes
    EXCITED = 2,   // wide open, high energy
    CURIOUS = 3,   // one brow raised, attentive
    SAD = 4,       // droopy, glistening
    SCARED = 5,    // wide eyes, shrunk pupils
    ANGRY = 6,     // narrowed, intense (mild for kids)
    SURPRISED = 7, // wide open, raised brows
    SLEEPY = 8,    // half-closed, slow blinks
    LOVE = 9,      // heart-shaped / warm glow
    SILLY = 10,    // cross-eyed or asymmetric
    THINKING = 11, // looking up/aside
    CONFUSED = 12, // puzzled, asymmetric mouth
};

enum class GestureId : uint8_t {
    BLINK = 0,
    WINK_L = 1,
    WINK_R = 2,
    CONFUSED = 3,
    LAUGH = 4,
    SURPRISE = 5,
    HEART = 6,
    X_EYES = 7,
    SLEEPY = 8,
    RAGE = 9,
    NOD = 10,
    HEADSHAKE = 11,
    WIGGLE = 12,
};

enum class SystemMode : uint8_t {
    NONE = 0,
    BOOTING = 1,
    ERROR_DISPLAY = 2,
    LOW_BATTERY = 3,
    UPDATING = 4,
    SHUTTING_DOWN = 5,
};

// ---- Per-eye state ----

struct EyeState {
    float openness = 0.0f; // 0=closed, 1=open (starts closed for boot)
    float openness_target = 1.0f;
    bool  is_open = true;

    float gaze_x = 0.0f;
    float gaze_x_target = 0.0f;
    float gaze_y = 0.0f;
    float gaze_y_target = 0.0f;
    float vx = 0.0f;
    float vy = 0.0f;

    float width_scale = 1.0f;
    float width_scale_target = 1.0f;
    float height_scale = 1.0f;
    float height_scale_target = 1.0f;
};

// ---- Eyelid overlay state (v2 model) ----

struct EyelidState {
    float top_l = 0.0f;
    float top_r = 0.0f;
    float bottom_l = 0.0f;
    float bottom_r = 0.0f;
    float slope = 0.0f;
    float slope_target = 0.0f;
};

// ---- Animation timers ----

struct AnimTimers {
    // Auto-blink
    bool  autoblink = true;
    float next_blink = 0.0f;

    // Idle gaze wander
    bool  idle = true;
    float next_idle = 0.0f;
    float next_saccade = 0.0f;

    // One-shot gestures (active + timer)
    bool  confused = false;
    float confused_timer = 0.0f;
    bool  confused_toggle = true;
    float confused_duration = 0.5f;

    bool  laugh = false;
    float laugh_timer = 0.0f;
    bool  laugh_toggle = true;
    float laugh_duration = 0.5f;

    bool  surprise = false;
    float surprise_timer = 0.0f;
    float surprise_duration = 0.8f;

    bool  heart = false;
    float heart_timer = 0.0f;
    float heart_duration = 2.0f;

    bool  x_eyes = false;
    float x_eyes_timer = 0.0f;
    float x_eyes_duration = 1.5f;

    bool  sleepy = false;
    float sleepy_timer = 0.0f;
    float sleepy_duration = 3.0f;

    bool  rage = false;
    float rage_timer = 0.0f;
    float rage_duration = 3.0f;

    bool  nod = false;
    float nod_timer = 0.0f;
    float nod_duration = 0.35f;

    bool  headshake = false;
    float headshake_timer = 0.0f;
    float headshake_duration = 0.35f;

    // Flicker (driven by confused/laugh)
    bool  h_flicker = false;
    bool  h_flicker_alt = false;
    float h_flicker_amp = 1.5f;
    bool  v_flicker = false;
    bool  v_flicker_alt = false;
    float v_flicker_amp = 1.5f;
};

// ---- Effects state (display-agnostic) ----

constexpr int MAX_SPARKLE_PIXELS = 48;
constexpr int MAX_FIRE_PIXELS = 64;

struct SparklePixel {
    int16_t x = 0;
    int16_t y = 0;
    uint8_t life = 0;
    bool    active = false;
};

struct FirePixel {
    float x = 0.0f;
    float y = 0.0f;
    float life = 0.0f;
    float heat = 0.0f;
    bool  active = false;
};

struct EffectsState {
    // Breathing
    bool  breathing = true;
    float breath_phase = 0.0f;
    float breath_speed = BREATH_SPEED;
    float breath_amount = BREATH_AMOUNT;

    // Boot sequence
    bool  boot_active = true;
    float boot_timer = 0.0f;
    int   boot_phase = 0;

    bool         sparkle = true;
    float        sparkle_chance = 0.05f;
    SparklePixel sparkle_pixels[MAX_SPARKLE_PIXELS]{};

    bool  afterglow = true;
    bool  edge_glow = true;
    float edge_glow_falloff = 0.4f;

    FirePixel fire_pixels[MAX_FIRE_PIXELS]{};
};

// ---- System display state ----

struct SystemState {
    SystemMode mode = SystemMode::NONE;
    float      timer = 0.0f;
    int        phase = 0;
    float      param = 0.0f; // e.g. battery level 0..1
};

// ---- Top-level face state ----

struct FaceState {
    EyeState     eye_l;
    EyeState     eye_r;
    EyelidState  eyelids;
    AnimTimers   anim;
    EffectsState fx;
    SystemState  system;

    Mood  mood = Mood::NEUTRAL;
    float brightness = 1.0f;
    float expression_intensity = 1.0f;
    bool  solid_eye = true;
    bool  show_mouth = true;

    // Talking animation (driven by supervisor during TTS playback)
    bool  talking = false;
    float talking_energy = 0.0f; // 0.0–1.0, current audio energy level
    float talking_phase = 0.0f;

    // Mouth state
    float mouth_curve = 0.2f;
    float mouth_curve_target = 0.2f;
    float mouth_open = 0.0f;
    float mouth_open_target = 0.0f;
    float mouth_wave = 0.0f;
    float mouth_wave_target = 0.0f;
    float mouth_offset_x = 0.0f;
    float mouth_offset_x_target = 0.0f;
    float mouth_width = 1.0f;
    float mouth_width_target = 1.0f;

    uint8_t active_gesture = 0xFF; // GestureId or 0xFF when idle.
    float   active_gesture_until = 0.0f;

    // Color override (set by system face animations, reset each frame)
    bool    color_override_active = false;
    uint8_t color_override_r = 0;
    uint8_t color_override_g = 0;
    uint8_t color_override_b = 0;
};

// ---- API ----

void  face_state_update(FaceState& fs);
float face_get_breath_scale(const FaceState& fs);
void  face_get_emotion_color(const FaceState& fs, uint8_t& r, uint8_t& g, uint8_t& b);

void face_blink(FaceState& fs);
void face_wink_left(FaceState& fs);
void face_wink_right(FaceState& fs);
void face_set_gaze(FaceState& fs, float x, float y);
void face_set_mood(FaceState& fs, Mood mood);
void face_set_expression_intensity(FaceState& fs, float intensity);
void face_trigger_gesture(FaceState& fs, GestureId gesture, uint16_t duration_ms = 0);
void face_set_system_mode(FaceState& fs, SystemMode mode, float param = 0.0f);

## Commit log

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2026-02-15 port IMU driver from LSM6DSV16X to BMI270
    The hardware uses a Bosch BMI270, but the driver was written for an
    STMicroelectronics LSM6DSV16X. This rewrites the driver to match the
    actual chip on the board:
    - Correct register map (CHIP_ID@0x00=0x24, data regs at 0x0C/0x12,
    config regs at 0x40-0x43, power at 0x7C-0x7D)
    - Correct I2C address (0x68 vs 0x6A)
    - Required 328-byte config file upload on init (max-FIFO variant from
    Bosch SDK, BSD-3-Clause)
    - Correct gyro sensitivity (65.5 LSB/dps at ±500 dps, was 17.50 mdps
    which is the LSM6DSV16X value — ~15% error in all gyro readings)
    - Proper BMI270 init sequence: soft reset → disable adv_power_save →
    config file burst-write → INT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
    [config.cpp, config.h, imu.cpp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]
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2026-02-16 Fix face boot loop and document Pi supervisor bring-up
    [face_state.cpp, face_ui.cpp, shared_state.h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]
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2026-02-18 fix: replace uv sync with uv pip install -e . to avoid rpi extra
    uv sync resolves ALL optional extras when building the lockfile, then
    installs them by default in uv 0.10.x. This drags in picamera2 ->
    python-prctl, which fails to build without libcap-dev headers.
    Switch to `uv pip install -e .` which installs only [project.dependencies]
    (no optional extras) and bypasses the lockfile entirely. picamera2 is
    a system package visible via --system-site-packages; it must not be
    pip-installed.
    Also add --allow-existing to uv venv to suppress the interactive
    "replace?" prompt on re-runs, and --seed to ensure pip is available.
    https://claude.ai/code/session_014oTEfKsRH3xR6qyTf3vrRG
2026-02-18 fix: wire MJPEG enable/disable, add vision diagnostics, add camera probe
    Three issues prevented camera video from working:
    1. MJPEG was never enabled. vision.set_mjpeg_enabled() was never called
    so the vision worker's encoding branch never ran. http_server.py now
    enables MJPEG when the first /video client connects and disables it
    when the last one disconnects, tracked via a nonlocal client counter.
    2. /debug/devices had no vision info. debug_devices() now includes
    vision.enabled, vision.alive (process health), fps, age_ms, and
    clear_confidence so you can see camera state without tailing logs.
    3. No camera probe. deploy/probe_camera.sh uses the venv Python to call
    Pic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
2026-02-18 feat: expose HSV tuning params and wire vision callbacks live
    param_registry.py:
    - Remove vision.mjpeg_enabled (MJPEG now auto-managed by /video client counter)
    - Add full floor HSV param set (h/s/v low+high) to match worker defaults
    - Add missing ball HSV upper bounds (s_high, v_high) that were never registered
    - Add vision safety threshold params: vision.stale_ms, vision.clear_low,
    vision.clear_high — now tunable at runtime without a restart
    policies.py:
    - Move vision thresholds to module-level mutable vars (_vision_stale_ms etc.)
    - Add configure_vision_policy() setter called when params change
    - apply_safety() now uses the live vars instead of hardcoded literals
    main.py:
    - Wire _VIS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
2026-02-21 fix face stuck on booting overlay
    The tick loop sent FaceSystemMode.BOOTING every tick during Mode.BOOT
    but never sent NONE on transition to IDLE, so the face MCU latched the
    booting overlay forever. Dashboard overrides were also immediately
    stomped.
    Track last-sent system mode (like v1 runtime) and only send on change.
    Skip auto system mode when face_manual_lock is on so the dashboard can
    override. Reset tracker on face disconnect for clean re-send.
    Also applies ruff formatting and removes unused AI_CMD_CANCEL import.
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2026-02-21 fix Orpheus TTS engine death and GPU memory leak on reset
    The orpheus_tts library calls asyncio.run() per generate request,
    destroying the event loop each time. vLLM's AsyncLLMEngine attaches
    persistent background tasks to that loop, so destroying it kills the
    engine after warmup. Fix by maintaining a dedicated persistent event
    loop thread in _TunedOrpheusModel and routing all vLLM calls through it.
    Also fix _reset_orpheus_backend to explicitly call engine.shutdown(),
    gc.collect(), and torch.cuda.empty_cache() so GPU memory is actually
    freed before retry — previously the EngineCore subprocess kept holding
    ~10 GiB VRAM as a zombie.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
2026-02-21 add hardware monitor tab to dashboard
    ROS2-inspired diagnostic dashboard with hierarchical status tree
    (OK/WARN/ERROR/STALE), Pi system resources via psutil, MCU
    communication health with packet rates and clock sync, battery
    voltage chart, sensor sparklines, fault flags, and worker status.
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2026-02-21 add clock sync between supervisor and MCUs
    The dashboard Devices tab showed both reflex and face clocks as
    "unsynced" because the supervisor never sent TIME_SYNC_REQ pings.
    All infrastructure existed (MCU handlers, state dataclass, API
    endpoint, dashboard UI) but the driving async task was missing.
    - Add ClockSyncEngine (PROTOCOL.md §2.2-2.4): sliding window,
    min-RTT offset estimation, state machine, drift filter
    - Add TIME_SYNC protocol types to protocol.py (0x06/0x86)
    - Support multiple on_packet handlers in SerialTransport
    - Wire engines into main.py asyncio.gather alongside tick loop
    - Handle TIME_SYNC_REQ in mock reflex for --mock mode
    - Fix dashboard SyncBadge case mismatch (SYNCED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
2026-02-21 add conversation state border system prototype in face sim
    ConvBorder state machine with 8 states (idle, attention, listening,
    PTT, thinking, speaking, error, done) — each with distinct color,
    animation, and LED sync. Border renders as 4px SDF frame with glow.
    Redesigned buttons: PTT (concentric arcs) and Cancel (X mark) with
    48px hit targets. Added talking phase-speed coupling (12+6*energy).
    Sim updated with F7-F12 conv state controls, LED indicator, and HUD.
    Not yet ported to firmware — pending v3 design review.
2026-02-21 add hey_buddy wake word model and training pipeline
    Train custom OpenWakeWord model using Piper TTS synthetic data, MIT RIR
    augmentation, and FMA background noise. V1 metrics: 71% accuracy, 42%
    recall, 0.27 FP/hour on synthetic test set — recall needs improvement
    via more samples and speech-heavy negatives.
    Includes:
    - training/setup.sh: one-shot environment setup (venv, repos, deps, data)
    - training/train.sh: 3-phase wrapper (generate → augment → train)
    - training/config.yaml: model config with negative phrases
    - supervisor_v2/models/hey_buddy.onnx: trained 201KB model
    Also removes obsolete planning docs (plan.md, supervisor_plan.md).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
2026-02-21 raise clock sync RTT threshold from 3 ms to 10 ms
    ESP32-S3 Full-Speed USB (12 Mbit/s) has a 1 ms host poll interval,
    giving typical round-trip times of 2-5 ms. The 3 ms threshold was
    rejecting most legitimate samples, causing both MCUs to oscillate
    between synced and degraded.
2026-02-21 per-device RTT threshold for clock sync: 50 ms for face MCU
    Face MCU has higher USB latency than reflex due to TinyUSB CDC ACM
    and LVGL display rendering (10-30 ms jitter). Make rtt_threshold_ns
    configurable per-engine so face can sync with its natural RTT range.
2026-02-21 face MCU: RGB565 canvas, sqrtf removal, afterglow off by default
    - Switch canvas from RGB888 (lv_color_t, 230KB) to RGB565 (pixel_t,
    153KB), saving 154KB PSRAM across canvas + afterglow buffers
    - Add pixel.h with inline RGB565 helpers (px_rgb, px_scale, px_blend)
    - Replace sqrtf() in rounded rect corners with integer squared-distance
    - Disable afterglow by default in g_cmd_flags (supervisor can re-enable)
    - Migrate system_overlay_v2 to pixel_t types
    [face_ui.cpp]
2026-02-22 fix dashboard monitor: clock state case mismatch + power panel no-data
    Clock sync states from the supervisor are lowercase (synced/unsynced/degraded)
    but MonitorTab compared against uppercase SYNCED/CONVERGING, causing Face MCU
    and clock badges to always show error. Extract clockLevel() helper with correct
    lowercase matching.
    PowerPanel now shows "No battery data (Reflex disconnected)" instead of a
    misleading 0 mV ERROR when reflex is not connected.
2026-02-22 face comm + personality engine: specs, research, and alignment review
    Complete body of work for face communication and personality engine design:
    - Face comm spec (Stage 1 + Stage 2), eval plan, impl plan
    - PE spec (Stage 1 + Stage 2), 8 research buckets (safety, temperament,
    memory, relationships, initiative, LLM selection, prompting, device split)
    - Alignment review: 5 conflicts resolved (guardrail enforcement tiered model,
    SURPRISED reclassified as Neutral, mood transition ownership clarified,
    CONFUSED mood added, queue model replaced with suppress-then-read)
    - Both specs amended in place, alignment report written
    - Face baseline inventory added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
2026-02-22 face sim V3: visual language definition + conformance remediation (G1–G7)
    Define the intended visual appearance of all 13 moods, 13 gestures, and
    8 conversation states in a design document (face-visual-language.md).
    Implement 7 conformance fixes: per-mood eye scale for all moods, dedicated
    NOD/HEADSHAKE gaze animations replacing laugh/confused reuse, THINKING→
    SPEAKING anticipation blink, ERROR gaze micro-aversion, eye scale reset
    parity with MCU, and Silly cross-eye intensity scaling.
2026-02-22 visual language review R1–R5: TN luma floor, spring bypass, coord space
    R1: Brighten SAD (70,110,210) and SLEEPY (70,90,140) for TN panel luma
    floor (L≥85). Add §1.3.1 hardware authoring note with full luma audit.
    R2: Move NOD/HEADSHAKE gaze writes to post-spring direct overrides,
    bypassing damped spring attenuation at high oscillation frequencies.
    R3: Add §1.5 coordinate space definition (+X=screen-right, +Y=down).
    R4: Document effective runtime maxima for guardrail-capped eye scales.
    R5: Add TTS timing annotation to THINKING→SPEAKING transition.
    Parity check: 70/70 (sim-ahead exclusions for SAD/SLEEPY colors).
2026-02-22 silhouette distinctiveness: matrix, clarity audit, mood pair fixes
    Add Silhouette Distinctiveness Matrix (13-mood × 4-channel table) and
    Clarity Audit sections to visual language spec. Resolve at-risk mood
    pairs: CURIOUS vs CONFUSED (opposite lid slope directions), LOVE vs
    HAPPY (convergence + stillness vs squint + wander), THINKING vs ANGRY
    (neutral geometry + gaze aversion vs compressed slit).
    Code changes:
    - CONFUSED: persistent mouth_offset_x (asymmetric "puzzled" mouth)
    - LOVE: mild pupil convergence (±2.5 gaze_x) + reduced idle wander
    (40% amplitude, 2.5-5.5s holds)
    - ANGRY: eye height 0.75→0.65 (deeper compression)
    - THINKING: eye width 0.95→1.0 (neutral, gaze aversion carrie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
2026-02-22 sim bugs + impl plan update: fix toggle/gaze override, rethink CURIOUS brow
    Fix 4 sim bugs sharing one root cause: _apply_conv_effects was calling
    face_set_flags every frame, overriding all keyboard toggles (gaze,
    glow, style, mouth) within one frame of being set.
    Fixes:
    - Apply CONV_FLAGS only on conv state transitions, not per-frame
    (matches real supervisor behavior: SET_FLAGS sent once per transition)
    - Skip conv gaze override when arrow keys held (manual_gaze flag)
    - CURIOUS: replace lid_slope -0.5 (looked scared/menacing) with
    asymmetric brow (CURIOUS_BROW_OFFSET=0.25, right eye slightly
    hooded → left appears "raised"). Lid slope doesn't produce a
    "raised brow" on stylized fa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
2026-02-23 face sim V4: corner button zones, icon library, animation expansion
    Replace circular PTT/cancel buttons with full corner-zone buttons (60x46px)
    featuring a swappable 6-icon library (mic, x-mark, check, repeat, star,
    speaker). Add 7 new gestures, system animations, speech rhythm sync,
    conversation backchannel, idle micro-expressions, and holiday modes.
    Fix justfile to use uv for sim, increase heart eye scale to match normal eyes.
2026-02-23 BMI270 IMU: full 6-DOF exposure, frame corruption fix, debug cleanup
    Fix BMI270 initialization (full 8192-byte config blob, proper INIT_ADDR
    chunked upload, post-reset timing). Suppress ESP_LOG before USB driver
    install to eliminate "frame too long" protocol corruption. Extend STATE
    telemetry with accel_x/y/z (int16 milli-g) across the full stack:
    ESP32 protocol, Python supervisor, mock, protocol capture, and dashboard
    accelerometer chart.
    [app_main.cpp, control.cpp, imu.cpp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]
2026-02-23 Phase 0: sync MCU firmware to V3 sim (17 divergences ported)
    Port all visual language divergences from the canonical V3 face
    simulator to ESP32 firmware, add CONFUSED mood end-to-end, and
    enforce parity via CI.
    Firmware:
    - Add Mood::CONFUSED (id=12) with targets, eye scale, color
    - Refactor per-mood eye scale into dedicated intensity-blended switch
    - Fix CURIOUS: remove lid_slope, add asymmetric brow + mouth_open
    - Add LOVE pupil convergence (±2.5) + reduced idle wander (40% amp)
    - Add CONFUSED persistent mouth_offset (2.0)
    - Rewrite NOD/HEADSHAKE as dedicated post-spring gaze animations
    - Brighten SAD/SLEEPY colors for TN panel luma floor
    Supervisor:
    - Add CONFUSED to FaceMood enum + exp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
    [face_state.cpp, face_state.h]
2026-02-23 Phase 2: conversation border renderer + SET_CONV_STATE (0x25)
    Full-stack implementation of animated conversation border on ESP32-S3
    face MCU. SDF frame+glow renderer (~700 lines C++) ported from sim
    border.py with band-optimized perimeter iteration. Per-state animations:
    sweep (ATTENTION), breathing (LISTENING/PTT), orbit dots (THINKING),
    energy-reactive (SPEAKING), flash+decay (ERROR), fade (DONE/IDLE).
    Pixel-rendered corner button zones replace LVGL overlay buttons — MIC
    and X_MARK SDF icons with IDLE/ACTIVE/PRESSED states, touch hit-testing
    in root callback. LED mirrors border color at 16% brightness.
    Supervisor side: protocol builder, face_client.send_conv_state(), and
    tick_loop wiri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
    [face_ui.cpp, shared_state.h]
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2026-02-23 fix supervisor freeze: restore USB CDC composite, add udev rules + diag tool
    Root cause: CONFIG_ESP_CONSOLE_NONE removed TinyUSB from the ESP32 build,
    changing the USB device from a CDC composite (cdc_acm driver) to a bare
    JTAG device, causing kernel-level write blocking that starved the asyncio
    event loop.
    Fix: restore CONFIG_ESP_CONSOLE_USB_CDC=y (proper composite device) and add
    CONFIG_ESP_CONSOLE_SECONDARY_NONE=y (prevents console text leaking into the
    binary protocol channel — the original "frame too long" culprit). Move
    esp_log_level_set to top of app_main as belt-and-suspenders.
    Also adds:
    - deploy/99-robot-buddy.rules: udev rule template for stable /dev/robot_reflex
    and /dev/ro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
    [app_main.cpp]
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2026-02-23 fix FreeRTOS tick crash: set CONFIG_FREERTOS_HZ=1000, guard task periods
    pdMS_TO_TICKS(2) returns 0 at the default 100 Hz tick rate, causing an
    immediate assertion failure in imu_task (xTaskDelayUntil requires
    xTimeIncrement > 0). Set tick rate to 1000 Hz and add period >= 1
    guards in imu, control, and range tasks as defense-in-depth.
    [control.cpp, imu.cpp, range_ultrasonic.cpp]
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2026-02-24 feat: suppress border/buttons during system overlays, drive corner button visuals
    - Firmware: guard conv_border_render + conv_border_render_buttons behind
    SystemMode::NONE check in face_ui_update (spec §4.4)
    - Firmware: disable corner button hit-testing + telemetry during system
    overlays via g_system_mode atomic check in touch callback
    - Firmware: drive corner button icon/state/color from conv state in
    conv_border_set_state (MIC+X_MARK per PTT/LISTENING/THINKING/SPEAKING)
    - Firmware: fix right button default icon from MIC to X_MARK
    - Sim: suppress border + button rendering during system overlays in
    render_face() via show_border guard
    - Parity tool: skip comment-referenced function c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
    [face_ui.cpp]
2026-02-24 feat: port Sim V3 face-based system screens to firmware
    Replace abstract full-screen system overlays (radar, glitch, etc.) with
    Buddy's face expressing system states — matching the Sim V3 approach.
    New files:
    - system_face.cpp/.h: face-state-driving functions for each SystemMode,
    ported from tools/face_sim_v3/render/face.py (_sys_* functions)
    - BOOTING: sleepy slits → yawn → blink → happy bounce (3s)
    - ERROR_DISPLAY: confused buddy with headshake + orange color
    - LOW_BATTERY: sleepy buddy with yawns at low charge + battery icon
    - UPDATING: thinking expression with gaze drift + progress bar
    - SHUTTING_DOWN: yawn → droop → close → fade to black (2.5s)
    - Small SDF ic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
    [face_state.cpp, face_state.h, face_ui.cpp]
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2026-02-24 fix: gaze bug + THINKING face refinement + mood sequencer timing params
    Fix dashboard gaze not reaching device: change face_client gaze scaling
    from *32 to *127 (full int8 range), remove 127/32 compensation
    workarounds in conv_state and tick_loop, and auto-disable idle_wander
    when manual lock is enabled so MCU doesn't override commanded gaze.
    Soften THINKING face to read as pensive instead of angry: reduce
    lid_slope 0.4→0.2, lid_top 0.2→0.08, neutralize mouth curve, increase
    gaze_y aversion, add slight eye height. Updated across all three parity
    locations (Python sim, MCU firmware, dashboard TS sim).
    Register mood sequencer timing as live-tunable params in the param
    registry (face.seq_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
    [face_state.cpp]
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2026-02-24 fix: register LVGL touch callbacks on canvas_obj instead of parent
    The full-screen canvas was marked LV_OBJ_FLAG_CLICKABLE but touch event
    callbacks were registered on the parent object. LVGL delivers events to
    the topmost clickable object, so the canvas absorbed all touches and the
    parent's callbacks never fired — making PTT and ACTION buttons completely
    dead. Register callbacks on canvas_obj directly.
    [face_ui.cpp]
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2026-04-26 firmware+supervisor: drop battery_mv from reflex protocol (Pi-side fuel gauge owns it now)
    Pi-side fuel gauge (Waveshare UPS HAT (B) INA219) is authoritative for
    battery state since the Phase 2 power-monitor work landed. The reflex
    MCU's battery_mv field never had a real ADC behind it (PIN_VBAT_SENSE was
    defined but no code wrote g_telemetry.battery_mv), so it just sent zeros
    on the wire. Drop it.
    Wire-format change: StatePayload (v1) shrinks 21 → 17 bytes, StatePayloadV2
    shrinks 27 → 25 bytes. struct format `<hhhhhhHHHB` → `<hhhhhhHHB`. No
    protocol-version bump — supervisor and firmware land together (per
    agreement). Old supervisor ↔ new firmware (or vice versa) won't parse
    each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
    [pin_map.h, shared_state.h]
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2026-06-26 kicad: power reflex board from Pi 5V via J9, fix cluster/row footprints
    J9 (Pi UART connector) extended from 3-pin to 4-pin (JST XH B4B):
    pin1=+5V pin2=GND pin3=TX pin4=RX
    This sources the +5V rail (ESP32-S3-Zero input, motor encoder power,
    HC-SR04) from the Pi's regulated 5V rather than adding a dedicated
    step-down regulator from VBAT.
    Footprint corrections in kicad-libs (shared with robot-scout):
    SparkFun_TB6612FNG_v2: row spacing 20.32mm → 15.24mm, confirmed
    from Eagle .brd JP1/JP2 placements.
    Waveshare_ESP32-S3-Zero_FlatMount: cluster pad x corrected from
    x=7.185/10.815mm to x=4.87/13.22mm, confirmed from STEP
    CYLINDRICAL_SURFACE r=0.70mm at (4.870,14.839) and (1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
    [robot-buddy-reflex.kicad_sch]
2026-06-26 kicad: fix DRC shorts, unconnected items, and dangling tracks
    PCB DRC improved from 97 violations / 3 shorts / 2 unconnected / 2 dangling
    to 90 violations / 0 shorts / 0 unconnected / 0 dangling.
    - /TRIG and /PWMA short (F.Cu): rerouted both nets through x=11.5 corridor
    - /ESTOP and +3V3 short (F.Cu): replaced zig-zag with F.Cu stub + via (29.8,20.75) + B.Cu
    detour up to y=9.0 (above /ENC_LA B.Cu vertical at x=27.509)
    - U1 pad 3 (+3V3) unconnected: added diagonal F.Cu track to (13.3,24.27)
    - C1 pad 2 (GND) unconnected: added F.Cu stub + via (29.1,23.02) to GND plane
    - Deleted orphan +3V3 segment (55.5,20.38)→(56.16,21.65)
    - Trimmed +3V3 horizontal to x=55.007 and extended verti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
    [robot-buddy-reflex.kicad_pcb]
2026-06-26 kicad: fix all DRC routing violations and export production gerbers
    Resolved all routing violations on the 4-layer reflex board:
    - Rerouted /TRIG to clear /PWMA diagonal (via x=12.1, right of U1 pad7)
    - Rerouted +3V3 B.Cu with tiny jog at x=28.312 to clear /ENC_LA buried via
    - Reverted /ECHO_MID from x=5.5 (shorted /ECHO_DIV) back to x=5.864
    - Rerouted /ENC_RB with y=24.67 jog to clear GND via at (30.975,25.49)
    - Rerouted /TRIG left section clear of U1 pad7 (/PWMA)
    - Fixed U2 silk pin label text height 0.6→0.8mm
    - Reverted /AIN1 to y=37.373 (impossible to clear both /AIN2 via and C4 GND pad;
    0.212mm gap is above PCBWay's 0.127mm manufacturing minimum)
    Remaining DRC: 4 clearance violatio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
    [robot-buddy-reflex-B_Cu.gbr, robot-buddy-reflex-B_Mask.gbr, robot-buddy-reflex-B_Paste.gbr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]
2026-06-26 kicad: shift C4 and R6 to clear final clearance violations
    Moved C4 down 0.1mm and R6 right 0.1mm to resolve the last 4 DRC
    clearance violations:
    - C4 (30.0,38.5→38.6): pad2 GND top edge now 37.81mm — 0.312mm gap
    to /AIN1 at y=37.373 (was 0.212mm, needed 0.250mm)
    - R6 (6.5→6.6, 34.0): pad2 GND left edge now 6.33mm — 0.341mm gap
    to /ECHO_MID vertical at x=5.864 (was 0.241mm, needed 0.250mm)
    Updated track endpoints to follow each pad: GND short-diagonal to
    existing GND via, +BATT stub on C4 pad1, /ECHO_MID endpoint on R6 pad1.
    DRC result: 0 clearance, 0 crossings, 0 shorts, 0 unconnected.
    Remaining 49 violations are silk/lib only — non-manufacturing.
    Regenerated gerbers at har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
    [robot-buddy-reflex-B_Cu.gbr, robot-buddy-reflex-B_Mask.gbr, robot-buddy-reflex-B_Paste.gbr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]
2026-06-27 kicad: swap J6 HC-SR04 connector from JST XH to 2.54mm pin header
    B4B-XH-A (2.5mm) replaced with PinHeader_1x04_P2.54mm_Vertical — HC-SR04
    modules use 0.1" header pins directly so no adapter harness needed.
    DRC clean (0 electrical errors).
    [robot-buddy-reflex.kicad_pcb]
2026-06-27 hardware: sync buddy schematic script to PCB layout
    J6 footprint: B4B-XH-A (JST-XH) → PinHeader_1x04_P2.54mm to match HC-SR04 pin header swap.
    J9: expand from 3-pin B3B-XH-A to 4-pin B4B-XH-A (add +5V on pin1; GND→pin2; TX→pin3; RX→pin4).
    Power symbols and net labels updated accordingly.
    [populate_schematic.py]
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2026-06-27 hardware: fix C6 NeoPixel bulk cap footprint to P2.00mm
    EEU-FM1A101 has 2.00mm lead spacing; P2.50mm would have been wrong.
    [robot-buddy-reflex.kicad_sch]
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2026-06-30 kicad: route buddy board clean; regen gerbers with kicad-cli extensions
    NeoPixel cluster shifted +5mm right in layout_pcb.py to clear SDA Qwiic
    via conflict at (19.16, 55.80) with old J10 pad 1 at (20, 57).
    route_pcb.py: POWER_W 0.50→0.40mm (R10/+5V clearance was 0.096mm <
    JLCPCB 0.1mm minimum); +3V3 patch horizontal moved to y=21.15 (was 21.40,
    too close to ESTOP via at (22.10, 22.04)); U2 pad-10 endpoint updated to
    (53.62, 21.65) after NeoPixel shift moved U2 left.
    Final DRC: 0 unconnected, 0 hard errors, worst clearance 0.129mm.
    Gerbers regenerated with kicad-cli (extensions now .gtl/.gbl/.g1/.g2
    etc. rather than .gbr); stale .gbr files removed; zip rebuilt clean.
    [robot-buddy-reflex-B_Cu.gbl, robot-buddy-reflex-B_Cu.gbr, robot-buddy-reflex-B_Mask.gbr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]
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
